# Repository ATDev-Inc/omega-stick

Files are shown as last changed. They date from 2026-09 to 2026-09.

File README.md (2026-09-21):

# Omega Stick

Omega Stick

**A low-force joystick for people with disabilities.** Omega Stick is an
accessible input device for computer control and gaming. Actuation force is
adjustable across roughly 5 to 25 grams and defaults to under 10.





This repository holds the **firmware**: an ESP-IDF project for the ESP32-S3,
written in C++20 on top of the [ESP++ (espp)](https://github.com/esp-cpp/espp)
component library.

## Contents

- [Why low force](#why-low-force)
- [Project status](#project-status)
- [Documentation](#documentation)
- [Hardware](#hardware)
- [Getting started](#getting-started)
  - [Prerequisites](#prerequisites)
  - [Build and flash](#build-and-flash)
  - [Expected output](#expected-output)
- [Repository layout](#repository-layout)
- [Contributing](#contributing)
- [License](#license)
- [Acknowledgements](#acknowledgements)

## Why low force

Conventional joysticks use a mechanical gimbal and centering springs. You have
to physically push against that spring on every input, and the force required is
typically well over 100 grams. For someone with limited strength, reduced range
of motion, tremor, or fatigue, that resistance is the difference between an
input device that works and one that does not.

Omega Stick removes the mechanical resistance from the sensing path. It uses a
**contactless 3-axis Hall-effect sensor** (TI TMAG5273) that measures the
position of a small magnet, so nothing has to be depressed, wiped, or deflected
against a spring to register movement. The actuation force is set by the return
mechanism alone, and is **adjustable from roughly 5 to 25 grams, defaulting
below 10**.

Adjustability matters as much as the floor. Vendors at the low-force frontier
report that a stick can be *too* light to control well, so the usable range
matters more than the minimum, and which point in it works is a property of the
person rather than the device. See D12 in [docs/decisions.md](docs/decisions.md).

Low force on its own is not what makes this project unusual: several sub-10 gram
sticks already ship. They are closed, mostly dealer-gated, and often unpriced.
The gap is the combination of low force with an open design, a plain USB HID
interface, a published price, and a published method for measuring the force
claim. See [docs/PRD.md](docs/PRD.md).

Because the sensing is contactless there is also nothing in the signal path to
wear out, which matters for a device someone may rely on daily.

The stick presents itself to the host over USB as a standard **HID** device, so
it works without drivers or vendor software on the host.

## Project status

**Early development.** This is pre-release firmware and the interfaces are not
stable yet.

What is in the tree today:

- A `TMAG5273` driver ([components/tmag5273/include/tmag5273.hpp](components/tmag5273/include/tmag5273.hpp))
  covering configuration, magnetic X/Y/Z reads, temperature, and conversion status.
- A sensor bring-up application ([main/main.cpp](main/main.cpp)) that probes the
  sensor, dumps its configuration, and streams live magnetic readings to the
  console.

Not implemented yet: the HID report descriptor, axis calibration and centering,
deadzone and response curve shaping, and the USB gamepad/mouse output path. The
`espp/hid-rp`, `espp/joystick`, and `espp/usb_device` dependencies are declared
in [main/idf_component.yml](main/idf_component.yml) in preparation for that work.

If you are looking for somewhere to help, those are the open areas. See
[CONTRIBUTING.md](./CONTRIBUTING.md).

## Documentation

Product and planning documents live in [docs/](docs/):

| Document | Contents |
| --- | --- |
| [PRD.md](docs/PRD.md) | What v1 is, who it is for, scope, and success metrics |
| [requirements.md](docs/requirements.md) | Functional and non-functional specification |
| [decisions.md](docs/decisions.md) | Product decisions with rationale, and what is still open |
| [compliance.md](docs/compliance.md) | What the project may and may not claim about itself |
| [status.md](docs/status.md) | Current working status |
| [research/](docs/research/) | Background research these were built from |
| [assets/logo/](assets/logo/) | Brand marks, wordmark, the animated hero scene, and usage notes |

Research documents are point-in-time snapshots and are not maintained.

## Hardware

The firmware currently targets:

| Part | Notes |
| --- | --- |
| MCU | ESP32-S3, configured via the ESP++ `qtpy` board support |
| Sensor | TI TMAG5273 3-axis Hall-effect sensor, I2C address `0x35`, 400 kHz |
| Bus | Qwiic / STEMMA QT I2C |
| Host link | USB, via TinyUSB |

The mechanical design, PCB, and enclosure are not part of this repository. If
you want to build one, open a
[discussion](https://github.com/ATDev-Inc/omega-stick/discussions) or an issue
and we will point you at what exists.

## Getting started

### Prerequisites

This is an ESP-IDF project targeting **ESP-IDF v5.5.1 or v6.0**. Follow the
[official ESP-IDF getting started
guide](https://docs.espressif.com/projects/esp-idf/en/release-v6.0/esp32s3/get-started/index.html)
to install the toolchain for your platform.

Component dependencies are pulled automatically by the IDF Component Manager
from [main/idf_component.yml](main/idf_component.yml); the resolved set is
pinned in [dependencies.lock](./dependencies.lock). You do not need to vendor
`espp` yourself.

### Build and flash

```console
idf.py set-target esp32s3
idf.py build
idf.py -p PORT flash monitor
```

Replace `PORT` with your serial port (`COM7` on Windows, `/dev/ttyACM0` on
Linux, `/dev/cu.usbmodem*` on macOS). Exit the monitor with `Ctrl-]`.

### Expected output

With a TMAG5273 connected on the Qwiic bus, the bring-up app prints the device
and manufacturer IDs, the active configuration, and then a live stream of
readings. Move a magnet near the sensor and the values should track it:

```
========================================
       TMAG5273 Driver Test
========================================
I2C Address: 0x35
========================================

Probing for TMAG5273...
TMAG5273 found!

X:    1.234 mT   Y:   -0.567 mT   Z:   12.345 mT   T:  24.50 C   Ready: YES
```

If you see `ERROR: TMAG5273 not found at address 0x35`, check the Qwiic cable
and confirm the sensor's address strap.

## Repository layout

```
main/                     application entry point and IDF component manifest
components/tmag5273/      TMAG5273 Hall-effect sensor driver
.github/workflows/        build, packaging, and static analysis CI
sdkconfig.defaults        project-wide ESP-IDF configuration defaults
```

## Contributing

Contributions are welcome, and not only code.

- **Are you a user of assistive technology?** Feedback about how the stick
  actually performs for you is the most valuable input this project can get. You
  do not need to know anything about programming or electronics to file
  [accessibility
  feedback](https://github.com/ATDev-Inc/omega-stick/issues/new/choose).
- **Are you a developer?** See [CONTRIBUTING.md](./CONTRIBUTING.md) for
  environment setup, code style, and the pull request process.

Everyone participating in this project is expected to follow the [Code of
Conduct](./CODE_OF_CONDUCT.md). To report a security issue, see
[SECURITY.md](./SECURITY.md).

## License

Released under the [MIT License](./LICENSE).

## Acknowledgements

Built on [ESP++ (espp)](https://github.com/esp-cpp/espp) and started from the
[esp-cpp/template](https://github.com/esp-cpp/template) project template, both
by [esp-cpp](https://github.com/esp-cpp).

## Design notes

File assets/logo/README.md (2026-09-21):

# Brand assets

Vector marks for Omega Stick. Every mark here is true vector: the omega outline
is 95 cubic Bezier curves with no straight segments, and the wordmark is drawn
rather than set -- straight lines and arcs, stroked with round caps -- so
nothing here depends on a typeface being installed. The folder also holds
two build scripts and three bitmaps, all noted below.

## Files

| File | Use |
| --- | --- |
| `omega.svg` | Primary mark, with outer glow. 96px and up |
| `omega-flat.svg` | Same mark without the blur filter. Below 96px |
| `omega-favicon.svg` | Silhouette only, no rim. Browser tab, 16px and up |
| `omega-mono.svg` | Single colour via `currentColor`. Silkscreen, laser, one-colour print |
| `wordmark.svg` | OMEGA STICK, neon gradient. Generated |
| `wordmark-mono.svg` | OMEGA STICK, single colour via `currentColor`. Generated |
| `lockup.svg` | Mark above wordmark. Default for headers and README. Generated |
| `scene.svg` | The scene as a still. Poster and hero art. Generated |
| `scene-mark.svg` | The same canvas and sky with the floor removed. Generated |
| `omega-neon.svg` | The mark alone with the neon-tube treatment, transparent. Dark grounds only. Generated |
| `scene.html` | The scene as a live hero: constructed mark, lit grid, power-on |
| `build-scene.py` | Regenerates the three scene files above from the constants `scene.html` uses |
| `build-wordmark.py` | Draws the alphabet and regenerates the two wordmarks and the lockup |
| `source-silhouette.png` | Two-colour bitmap the outline was traced from. Kept so the trace is reproducible |
| `source-scene.png` | The render the scene was matched to. Provenance, not a spec |
| `source-scene-knockout.png` | The same render with its background knocked out |

## Palette

| Stop | Hex |
| --- | --- |
| 0% | `#FF12E8` |
| 24% | `#C022FF` |
| 50% | `#7A3BFF` |
| 76% | `#2A8CFF` |
| 100% | `#25D8F2` |

Background used in the scene: `#0B0A2E`. Every scene file lays a sky gradient
over it rather than using it flat -- `#0A0730` overhead to `#1B0A5E` at the
horizon in `scene.html` and `scene.svg`, a shorter ramp in `scene-mark.svg`
which has no horizon -- so sampling a pixel out of a render will not give you
`#0B0A2E`. Use it as the surrounding page colour, not as a colour to match.

## Usage notes

- **Do not scale `omega.svg` below about 96px.** Its Gaussian blur turns to
  mush at small sizes. Use `omega-flat.svg` or `omega-favicon.svg` instead.
  This was checked by rendering both, not assumed.
- **`omega-mono.svg` and `wordmark-mono.svg` inherit `currentColor`**, so set
  `color` on the parent rather than editing the file. That only works when the
  SVG is inlined in the page. Referenced through `<img>` it is a separate
  document, inherits nothing, and comes out black -- so on a dark ground reach
  for `wordmark.svg`, or inline the file.
- **The wordmark is stroked, not filled.** One path of straight lines and
  arcs, `stroke-linecap` and `stroke-linejoin` both `round`, at
  `stroke-width` 17% of the cap height. That is the whole letterform: the round
  terminal is the same tube the mark reads as, which is what makes the two look
  like one drawing in the lockup rather than a symbol next to some type. It
  also means the file stays under 2 kB and the weight is one number.
  **For laser, CNC or vinyl, expand the stroke to outlines first** -- those
  toolpaths follow a stroked path as a centreline and will cut the skeleton
  rather than the letters.
- **The S is the one letter that is not plainly circles and lines.** Each half
  is walked out from the waist as a chain of tangent arcs whose radius tightens
  into the left extreme and opens back out over the top, so the curvature falls
  towards zero at the inflection instead of the letter carrying a straight
  segment through its middle. Its proportions are measured off Century Gothic,
  a geometric face with a truly circular O: there the S is 0.56 of the O's
  width, and this one is 0.62 because a much heavier stroke needs the extra
  room for its counters. The docstring in `build-wordmark.py` records two
  constructions that looked reasonable and were not, so they do not get tried
  again.
- **The S's lower half is wider than its upper half, deliberately.** Draw the
  two congruent and the letter measures symmetrical but reads top-heavy, the
  usual illusion in S, B, X and 8. Every face measured corrects it, by 1.06 in
  Corbel and Verdana up to 1.16 in Century Gothic; this sits at 1.095. The
  waist is nudged left of centre to buy that, and up a little to put the
  inflection where the references put it, both through one `WAIST` constant.
  If the S ever looks wrong at the bottom, check that before the curves: the
  bug people expect is the two halves having drifted apart, and the bug that
  actually shows is them being identical.
- **Nothing in the wordmark is a declared width.** The letters are drawn in a
  100-unit cap height; each one's ink box and both its sidebearings are then
  measured off the shape. A side gets a full bearing where its silhouette is
  flat and less of one the further that silhouette recedes, so `T` tucks under
  its neighbour and `O` sits closer than `I` without anybody kerning pairs by
  hand. Change the weight and the spacing re-solves with it.
- **The round letters are bigger than the cap height, on purpose.** `O`, `C`,
  `G` and `S` overshoot the cap line and the baseline by 1.3 units in 100, and
  the points of `A` and `M` do the same; a circle that stops exactly on the cap
  line reads as too small beside a flat-topped letter. `O`, `C` and `G` stay
  true circles at any weight because their radius is derived from the overshoot
  rather than typed in.
- **The traced outline lives in one place.** All eight SVGs that draw the mark
  carry it byte for byte, and both build scripts read it out of `omega-mono.svg`
  at build time rather than keeping a copy of their own.
- **Mind which space a gradient is in.** The hand-drawn marks use
  `userSpaceOnUse`, and there the rule is: keep the geometry in one coordinate
  space. Wrap parts of a mark in their own transformed groups and each group
  restarts the gradient in its own space, so every piece renders one flat
  colour. The three scene files cannot do that -- the mark and its
  reflection have to sit in differently transformed groups -- so their neon
  gradient is `objectBoundingBox` instead, which is measured per element and
  survives the transform. Copy the right one for the situation.
- `scene.svg` and `scene.html` carry the grid and are deliberately the only
  files that do. The grid is decoration; the mark has to work without it.
- **The wordmark files are generated too; edit `build-wordmark.py`, not them.**
  Run `python assets/logo/build-wordmark.py` to rebuild `wordmark.svg`,
  `wordmark-mono.svg` and `lockup.svg`. It reads the traced outline out of
  `omega-mono.svg` for the lockup, the same way `build-scene.py` does, so the
  trace still lives in exactly one place. The lockup sizes the mark and the gap
  in wordmark cap heights, measured off the mark's real ink box rather than its
  viewBox -- the mark files carry a margin for their glow, and laying out
  against that would put the mark further away than the number says.
- **Three scene files are generated; edit `build-scene.py`, not them.** Run
  `python assets/logo/build-scene.py` to rebuild `scene.svg`, `scene-mark.svg`
  and `omega-neon.svg`. The camera, framing and palette constants at the top of
  that script mirror the custom properties at the top of `scene.html`, so
  `scene.svg` and `scene.html` stay the same picture. They drifted
  badly once -- the SVG had the mark at 55.5% of the frame width against the
  HTML's 38.9%, with the feet on the horizon rather than in front of it and the
  grid at half the pitch -- which is why the geometry is now derived rather than
  drawn. Change one, change the other.
- **The two still differ in the mark outline, on purpose.** `scene.svg` uses the
  traced outline shared with `omega.svg` and the rest of this folder;
  `scene.html` constructs its own from ellipses. They part company slightly
  around the feet. Everything else -- camera, framing, colour ramp, glow, haze,
  reflection, vignette -- matches to a mean of 14/255 per pixel across the
  frame, measured by rendering both.
- **`scene.html` draws the mark from construction, not from the trace.** Outer
  contour: one ellipse. Counter: two half-ellipses sharing a radius, the lower
  one longer. Feet: axis-aligned slabs. It is symmetric about its centre, which
  the traced outline in the other files is not.
- **`scene.html` is switched by data attributes on `.omega-scene`**, and the
  tunable dials are custom properties documented at the top of the file.

  | Attribute | Effect |
  | --- | --- |
  | `data-bg="transparent"` | Drop the sky, stars and vignette, for compositing |
  | `data-motion="calm"` | Still grid, rest of the scene alive. **The default** |
  | `data-motion="on"` | Add the grid drift back on top of the default |
  | `data-motion="off"` | Freeze everything, as `prefers-reduced-motion` does |
  | `data-intro="off"` | Skip the power-on, keep the idle breathe and twinkle |
  | `data-stars="off"` | Drop the starfield, back to flat negative space |
  | `data-crt="on"` | Scanlines and film grain over the whole frame |

- **The grid holds still by default, and that is deliberate.** Perspective
  squares the line weight, so a depth line lands on screen at
  `--lw-z * cos(tilt) * (1 - u)^2` and falls under a pixel wide past `u = 0.61`.
  A sub-pixel line cannot move without its coverage stepping, which reads as
  flicker. Softening the line profile (`--soft-z`), fading the far field where
  lines stop being resolvable, and low-passing the floor together cut the
  measured shimmer by about half -- not enough, so the drift is off unless asked
  for. `data-motion="on"` restores it and `--drift` sets its speed.
- **`omega-neon.svg` needs a dark ground; `omega.svg` does not.** The neon
  treatment is a white rim plus an inner tube highlight and an outer halo, and
  all three of those depend on the background being darker than they are. On a
  near-white card the rim disappears into the page and the halo does nothing,
  leaving a shape that reads as cut out rather than lit. Checked by rendering
  both marks over ink, near-white and mid-violet. Use `omega.svg` on light
  backgrounds and `omega-neon.svg` on dark ones; they share a viewBox and
  intrinsic size, so swapping one for the other moves nothing in a layout.
- **`scene-mark.svg` is the scene with the floor taken out**, not a crop of it.
  The mark recentres, and the sky loses the two light pools anchored to the
  horizon in favour of one centred on the mark -- otherwise the frame reads as
  a scene whose floor failed to load. It is the file to reach for when the
  README note above about the grid being decoration needs demonstrating.
- **The scene was matched to `source-scene.png` by eye, not by measurement,**
  and it cannot be measured. The reference is a soft, glow-heavy render with
  no crisp edge anywhere on the mark: threshold it five different ways and
  the mark's width comes out anywhere from 37% to 55% of the frame, because
  near the feet its bloom floods almost the full width and the horizon band
  below it is brighter than the mark's own rim. `scene.html` settles on
  38.4%, which sits at the sane end of that range. The constants at the top
  of `scene.html` are the authority for framing; these two PNGs are kept as
  provenance, so do not re-derive geometry from them.
- **Set `data-intro="off"` before screenshotting `scene.html`.** The power-on
  runs for 3.2s from load and its first keyframe is a black frame, so a headless
  capture -- which freezes CSS animations at t = 0 -- otherwise gets the unlit
  scene. This was hit while rendering the file, not guessed at.
- **The plane's colour stops are pre-distorted and are tied to `--depth`.** The
  gradient runs down a plane that is then foreshortened, so evenly spaced stops
  would pile up against the horizon. The stops in the file invert that map for
  the current `--depth`; change the depth and they have to be re-solved, or the
  floor's cyan-to-magenta ramp lands in the wrong place. `--fade` is tied to
  `--depth` the same way, and is called out where it is set.

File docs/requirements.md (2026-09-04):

# Omega Stick v1: requirements

Supporting document to [PRD.md](PRD.md). This is the detailed specification;
the PRD is the one-page summary.

Priority: **[M]** must-have for v1, **[S]** should-have, **[C]** could-have.

Evidence behind these requirements is in [docs/research/](research/).

---

## 1. Sensing and signal path

- **SEN-1 [M]** Sample the TMAG5273 X and Y channels continuously at **≥1 kHz**
  from a dedicated pinned FreeRTOS task.
- **SEN-2 [M]** Use the ±40 mT range (x1 part) with **CONV_AVG = 4x**
  (≈3.1 kSPS 3-axis), which gives real noise reduction while staying ~3x faster
  than the sample requirement.
- **SEN-3 [S]** Add an XY-only 4-byte burst read. The driver currently bursts 6
  bytes from `X_MSB_RESULT`; XY-only is ≈158 µs against ≈202 µs at 400 kHz.
- **SEN-4 [S]** Use the sensor's `INT` pin as data-ready if the board exposes it,
  rather than polling on a timer.
- **SEN-5 [M]** Detect sensor loss (I2C failure, or conversion-ready stuck)
  within **500 ms** and surface it per STA-2.
- **SEN-6 [M]** On sensor loss, hold all axes at center rather than transmitting
  the last value or garbage. A stuck-full-deflection axis is an actively harmful
  failure for someone driving a pointer.

## 2. Calibration and centering

- **CAL-1 [M]** Capture a center reference at boot from the resting position.
- **CAL-2 [M]** Provide a guided calibration routine invoked **on the device
  itself**, requiring no host software and **no dedicated control**: capture
  center, then capture the user's reachable extents per axis. Invoked by a stick
  gesture (for example, hold full deflection in one corner for 3 seconds), so it
  costs nothing in the BOM and works with no computer attached. Also invocable
  from the configuration page (CFG-1).
- **CAL-3 [M]** Calibration must be completable by a user who cannot see a
  console. Signal each stage through STA-1.
- **CAL-4 [M]** Map the user's *actual* reachable range to full output range,
  per axis and independently. A user who can reach 30% travel left and 80% right
  must still get full output in both directions.
- **CAL-5 [M]** Slow idle drift correction: when input sits within the deadzone
  for a configurable dwell, migrate the center reference at a rate slow enough
  that it cannot fight deliberate sustained input.
- **CAL-6 [M]** Persist calibration to NVS and restore on boot (see PER-1).
- **CAL-7 [S]** Provide a one-action reset to factory defaults that does not
  require a host.

> Runtime re-centering is mandatory because the TMAG5273 has **5% typical
> sensitivity drift** across temperature, and its on-chip offset registers are a
> static trim rather than drift tracking.

## 3. Response shaping

- **RSP-1 [M]** Configurable center deadzone, radial, default small but nonzero.
- **RSP-2 [M]** Configurable outer (range) deadzone, so full output is reached
  before mechanical end-stop.
- **RSP-3 [M]** Selectable response curve: linear (default) and exponential.
  `espp::FloatRangeMapper` is linear only; `bezier.hpp` is the building block for
  the curve.
- **RSP-4 [M]** Per-axis inversion and axis swap, for users mounting the device
  at an arbitrary orientation.
- **RSP-5 [S]** Per-axis gain scaling. Gain adjustment is one of the few tuning
  parameters with a measured, statistically significant benefit for this
  population (p<0.05, n=16).
- **RSP-6 [S]** Single-axis lock mode, for users who cannot isolate one axis from
  the other.
- **RSP-7 [C]** Selectable tremor filter, **default off**, user-defeatable, with
  the ability to A/B it without a host.

> Tremor filtering defaults off because the one controlled trial of adaptive
> (WFLC) filtering found **no performance improvement** and possible damping of
> intended motion. Fixed low-pass is worse: MS tremor at 3.5 to 5.0 Hz overlaps
> intentional movement.

## 4. Host output

- **OUT-1 [M]** Enumerate as a USB HID device requiring no driver installation on
  Windows 10/11, macOS, Linux, ChromeOS, and Android.
- **OUT-2 [M]** Gamepad report: X/Y (left stick), Z/RZ (right stick), 4-bit hat,
  and buttons.
- **OUT-3 [M]** Mouse report: relative X/Y motion plus at least left and right
  buttons.
- **OUT-4 [M]** Mode selection between gamepad and mouse is made **from the host**
  via the configuration surface (CFG-1), not from a control on the device. The
  selection **persists to NVS** and is restored on boot, so the device keeps its
  mode when later connected to a host that cannot configure it (XAC, console,
  tablet). Switching must not cause re-enumeration.
- **OUT-5 [M]** Set HID `bInterval` to **1 ms**. `espp::UsbDevice`'s
  `HidFunction` defaults `poll_interval_ms` to 10, which is only 100 Hz. **This
  default must be overridden explicitly.**
- **OUT-6 [M]** Send reports on change, decimated from the ≥1 kHz sample task.
- **OUT-7 [M]** Keep HID reports **at or under 64 bytes**. There is a known
  ESP-IDF endpoint-stall defect with consecutive reports above 64 bytes.
- **OUT-8 [M]** Expose the interface the configuration page needs (WebHID feature
  reports, or a WebUSB vendor interface) in the same TinyUSB composite. **Raised
  from [S] to [M] because CFG-1 now depends on it.** Also expose a CDC-ACM
  interface for logging and a fallback configuration CLI, for developers and for
  users whose browser cannot reach the config page.
- **OUT-9 [S]** Verify against the XAC's documented external-joystick mapping
  (X/Y to left stick, Z/RZ to right stick, hat to d-pad), which requires **XAC
  firmware June 2024 or newer**. Default button mapping for external USB joystick
  buttons is reported as unexpected and needs bench confirmation.

## 5. Configuration

- **CFG-1 [M]** Configuration is performed from a **browser-based configuration
  page requiring no installed software** (WebHID or WebUSB). Every parameter in
  sections 2 and 3 marked [M], plus output mode (OUT-4), is settable there.
- **CFG-2 [M]** Every setting **persists to NVS** (PER-1) and survives replug,
  power loss, and a change of host. A user configures once on a computer and the
  device keeps that configuration on an XAC, console, or tablet.
- **CFG-3 [M]** The device is fully functional at first plug-in with factory
  defaults. Configuration is never a prerequisite.
- **CFG-4 [M]** The configuration page must be usable by someone operating the
  computer with the Omega Stick itself, or with whatever input device they
  already use. Large targets, keyboard-reachable, no drag-only interactions, no
  timed interactions. It is an accessibility product: its own settings UI is the
  first thing a user touches.
- **CFG-5 [S]** Support at least two stored profiles (for example a gaming
  profile and a pointer profile).

> **Design principle 2 ("no required host software") is satisfied in spirit but
> narrowed.** A browser page installs nothing, but it does make the *changing* of
> settings host-dependent. CFG-2 is what keeps the device itself
> host-independent: the configuration travels with the device, not the host.
> **CAL-2 deliberately stays on-device**, because recalibration is the one thing
> a user may genuinely need in the field with no computer present.

## 6. Status and failure visibility

- **STA-1 [M]** A non-console status channel (LED or equivalent) that
  distinguishes at minimum: healthy, calibrating, calibration stage advanced,
  sensor fault, and configuration saved.
- **STA-2 [M]** Sensor faults, calibration faults, and NVS faults are each
  distinguishable through STA-1, not merged into one generic error.
- **STA-3 [S]** Status must be perceivable without relying solely on color, since
  the user population overlaps with color vision deficiency.

## 7. Persistence

- **PER-1 [M]** Calibration, configuration, and **selected output mode** persist
  in NVS across power cycles, host changes, and firmware updates within a major
  version. This is what makes host-side configuration (CFG-1) acceptable on hosts
  that cannot configure.
- **PER-2 [M]** Corrupt or absent stored configuration falls back to defaults and
  reports through STA-2, rather than failing to boot.
- **PER-3 [S]** Store a schema version so future firmware can migrate or safely
  reject old records.

## 8. Non-functional

- **NFR-1 [M]** End-to-end latency, stick motion to HID report on the wire,
  **≤5 ms** at the 95th percentile. The computed budget is ~2 to 3 ms at a 1 ms
  bInterval; the sensor and I2C path together are under 0.5 ms and are never the
  bottleneck.
- **NFR-2 [M]** Sustained operation for **≥8 hours** with no drift requiring
  manual recalibration.
- **NFR-3 [M]** No dynamic allocation in the sample or report path.
- **NFR-4 [S]** Set `CONFIG_FREERTOS_HZ=1000` and 240 MHz CPU in
  `sdkconfig.defaults`. Both are currently commented out.
- **NFR-5 [S]** Sustained 1 kHz HID reporting on ESP32-S3 + TinyUSB is
  **unverified**; no published benchmark was found. Bench-measure early and
  revise NFR-1 if it proves unattainable.

---

## 9. Hardware interface requirements

**Not owned by this repository.** Stated because the product claims depend on
them. See the scope note in the [PRD](PRD.md).

- **HW-1 [M]** Actuation force **adjustable across approximately 5 to 25 gf**,
  with the shipped default **at or below 10 gf**. Pending the design-principle
  decision in the PRD.
- **HW-2 [M]** A **documented, repeatable force and throw measurement protocol**,
  published with results. ISO 9241-410 (ergonomic design of physical input
  devices, explicitly covering joysticks) is the natural framework to cite.
  No competitor publishes a method; several disagree with third-party
  measurements of their own products.
- **HW-2a [M]** The protocol must be **performable by the person who printed the
  device, using household items** (for example a set of known small masses or a
  kitchen scale), not laboratory equipment. Because the enclosure is 3D printed
  by third parties, this is not documentation, it is the **only quality control
  the design has**. See HW-9.
- **HW-3 [M]** Mounting: **1/4"-20 UNC insert** plus the **AMPS 4-hole pattern
  (30 mm x 38 mm)**. That combination reaches RAM Mounts (1" B ball is the
  practical AT size), the Rehadapt Universal Device Socket (and through it
  VESA 75/100, Daessy, Armon Edero, LC-Tech), and matches the Xbox Adaptive
  Joystick convention. Negligible BOM cost, large ecosystem reach.
- **HW-4 [S]** Compatibility with the special-controls ecosystem's 6 mm rod and
  half-clamp hardware.
- **HW-5 [M]** USB bus-powered, **no battery**. A cell would trigger UN 38.3
  transport and IEC 62133-2 product-safety obligations for no v1 benefit.
- **HW-6 [M]** Expose the TMAG5273 `INT` pin to a GPIO (enables SEN-4).
- **HW-7 [S]** Magnet and sensor geometry chosen so that full mechanical throw
  maps to a large fraction of the ±40 mT range, maximizing usable resolution of
  the 12-bit ADC (one LSB ≈ 19.5 µT at that range).
- **HW-8 [M]** User-replaceable wear parts, with spares and drawings published.
  Since the body is printed, a worn part should be **reprintable rather than
  ordered**. Repairability is a direct countermeasure to the documented
  abandonment predictors.
- **HW-9 [M]** **Design for print-tolerance variance.** At a 5 to 10 gf budget,
  friction in the return mechanism is most of the specification, and print
  tolerance, layer adhesion, and surface finish vary between machines, materials,
  and successive prints on one machine. A few grams of unintended friction
  consumes the entire budget. Required:
  - Publish tested filament types, layer heights, orientations, and tolerances,
    and state which are known not to work.
  - Prefer **non-printed parts for the friction-critical path** (bearings,
    bushings, pivots, and the return element itself) sourced as standard
    off-the-shelf components, so the printed part positions them rather than
    being the tribological surface.
  - Provide a **printed test coupon or go/no-go gauge** so a builder can check
    their printer before committing to a full build.
  - Publish the acceptance criterion the HW-2a measurement has to meet.
- **HW-10 [S]** Magnet-to-sensor geometry should be **tolerant of the stack-up
  variance a printed assembly introduces**. Firmware calibration (CAL-4) already
  maps each user's actual reachable range, which absorbs a useful amount of
  per-unit geometric variation for free; the mechanical design should lean on
  that rather than demand tight tolerances it cannot enforce.

---

## 10. Host compatibility matrix

| Host | Gamepad mode | Mouse mode | Notes |
| --- | --- | --- | --- |
| Windows 10/11 | Yes (DirectInput / `RawGameController`, appears in `joy.cpl`) | Yes | **Not XInput.** Many modern titles are XInput-only and will not see it. Steam Input is the documented workaround |
| macOS | Yes (IOKit HID) | Yes | **Not `GCController`.** Apple's GameController.framework gates on MFi/Xbox/DualSense PnP IDs; generic pads produce no controller object. Open Apple bug on file |
| Linux | Yes (evdev/joydev) | Yes | Essentially unclaimed by competitors |
| ChromeOS | Yes | Yes | |
| Android | Yes (`SOURCE_GAMEPAD`) | Yes | |
| **iOS / iPadOS** | **No** | **Yes** | Mouse via AssistiveTouch pointer is fully supported and is **the only working mode**. Reports suggest exotic composite descriptors can make iOS ignore a device entirely: bench-verify early |
| Xbox (via XAC USB-A) | Yes | n/a | Requires XAC firmware June 2024+. No licensing needed |
| Xbox (direct) | **No** | **No** | Blocked, error `0x82d60002` |
| PlayStation 4/5 (direct) | **No** | **No** | Requires cryptographic auth |
| Nintendo Switch (direct) | **No** | **No** | Requires proprietary handshake |

Full analysis: [research/03](research/03-hid-platform-compatibility.md).

---

## 11. Known defects to fix first

Found while surveying the existing driver. Both block milestone M-A.

### DEF-1: magnetic range conversion is wrong for every part variant

[`components/tmag5273/include/tmag5273.hpp:770`](../components/tmag5273/include/tmag5273.hpp#L770)
returns `266.0f` unconditionally, and
[line 754](../components/tmag5273/include/tmag5273.hpp#L754) consumes it as the
**LOW** full-scale, doubling it for HIGH. That yields LOW = 266 mT / HIGH = 532
mT, which matches neither variant:

| Part | LOW | HIGH |
| --- | --- | --- |
| A1 | ±40 mT | ±80 mT |
| A2 | ±133 mT | ±266 mT |
| **Code produces** | **266 mT** | **532 mT** |

Reported values are therefore **~6.65x high on an A1** and **~2x high on an A2**.
The in-code comment acknowledges the hardcoding.

### DEF-2: `range_z_mT()` is dead code

[Line 773](../components/tmag5273/include/tmag5273.hpp#L773) is never called.
`convert_raw_to_mT` always reaches for the XY constant even when callers
correctly pass `z_range_`. Numerically harmless only because both constants are
currently the same literal, which stops being true the moment DEF-1 is fixed in
isolation.

> Because joystick math runs in **raw counts**, neither defect can affect how the
> device feels. Both corrupt any published measurement and any bench validation,
> which matters because HW-2 makes a published force protocol part of the
> product's positioning.

### Also unused, worth wiring

- `INT_CONFIG_1`: enables SEN-4 (data-ready interrupt)
- `MAG_OFFSET_CONFIG_1/2`: on-chip static trim, distinct from runtime re-centering
- `MAG_GAIN_CONFIG`

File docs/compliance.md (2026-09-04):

# Omega Stick v1: claims and compliance constraints

Supporting document to [PRD.md](PRD.md). These are constraints on **what the
project may say**, which is why they belong alongside the product spec rather
than in a separate legal file.

**Not legal advice, and not a regulatory analysis.** This records what the
project will and will not claim about itself. Supporting research on funding and
product compliance is in [research/04](research/04-funding-and-compliance.md).

**Point-in-time snapshot.** Compiled during v1 planning and not actively
maintained. Re-check anything here before relying on it.

---

## 1. Prohibited claims

Omega Stick v1 must be described **only** as a computer and gaming input
peripheral for accessibility. Specifically prohibited:

- Any **therapeutic, diagnostic, rehabilitative, or treatment** claim.
- Any claim positioning it as a **communication device for people with medical
  impairments**.
- Any **wheelchair drive-control** capability.
- **"ADA compliant."** The ADA creates obligations for covered entities rather
  than a product certification, so there is no such mark for a peripheral to
  carry. (Inference from how the statute is structured, UNVERIFIED.)

### Why this is a hard constraint, not a style preference

Medical, therapeutic, and communication-device claims carry obligations that a
general-purpose input peripheral does not. How a product describes itself is
what determines which category it lands in, so the wording is a product
constraint rather than a matter of marketing taste.

This project has taken no regulatory advice and nothing here substitutes for it.
If the scope ever moves toward a medical or communication device, that needs
qualified counsel before anything ships.

Keep a documented prohibited-claims list and review published copy against it.

### The wheelchair line

Wheelchair drive control is a hard non-goal, not a deferred feature. A drive
input is a safety-critical part of a mobility system, which is a different
product category carrying a different set of obligations.

---

## 2. Compliance obligations for v1 as scoped

Wired, USB bus-powered, no radio, no battery:

| Region | Obligation |
| --- | --- |
| **US** | FCC Part 15 Subpart B, Class B, authorized by **SDoC**. Requires a US responsible party, a compliance information statement, and labeling |
| **EU** | EMC Directive 2014/30/EU, RoHS, REACH, WEEE producer registration. **RED does not apply** without a radio |
| **UK** | Accepts CE indefinitely (2024 extension) |

### Not applicable at this scope

RED, UN 38.3, IEC 62133-2, and modular radio integration paperwork.

> **All of these arrive the moment BLE or a battery ships.** That is the main
> practical reason for decisions D1 and HW-5.

### USB identifiers

| Option | Cost |
| --- | --- |
| USB-IF VID | **$6,000**, sharing forbidden |
| **Espressif VID `0x303A`** | **Free**, PID allocated by pull request |
| pid.codes | Free, fallback |

### If BLE ever ships

FCC clarified that open-source firmware is permitted **as long as it cannot
alter RF operating characteristics**. Architect the firmware now with a
separated RF/config layer so a future BLE variant does not force the project
closed.

---

## 3. Standards to cite

| Standard | Use |
| --- | --- |
| **ISO 9241-410** | The framework for the HW-2 force and throw measurement protocol. Explicitly covers joysticks |
| **ISO 9999** | Assistive product class, for tender and catalog documentation |
| **Section 508 Chapter 4 (Hardware)** and **EN 301 549** | Publish a **VPAT / Accessibility Conformance Report** |

> Institutional and government buyers ask for a VPAT, and **its absence blocks
> procurement outright.** EN 301 549, unlike WCAG, contains substantial hardware
> requirements and is what buyers cite for physical products.

---

## 4. Open source

- **Keep MIT** for firmware. Obligations are minimal and fully compatible with
  selling hardware.
- **Audit and preserve upstream third-party NOTICE files** before shipping
  binaries. ESP-IDF components are largely Apache-2.0.
- **Pursue OSHWA certification.** Free, self-certifying, annually renewed. The
  TMAG5273 has a public TI datasheet, so the third-party documentation condition
  is satisfiable. It is a credible trust signal to AT funders and the disability
  community, and the nearest competitor (Willow) already holds one.

**No conflict** was found between open sourcing and the compliance regimes that
apply to v1 as scoped. Two friction points only:

1. If BLE ships, RF parameters must not be user-modifiable.
2. If the product scope ever changed such that a formal quality system applied,
   community pull requests would need a gated release process feeding a
   controlled build.

---

## 5. Funding pathways

**Do not build the business case on Medicare.** General-purpose computer access
fails the "primarily and customarily used to serve a medical purpose" test, and
devices that can be unlocked for general computing are coded **A9270,
non-covered**.

### Realistic channels for v1

| Channel | Notes |
| --- | --- |
| **State AT Act programs** | ACL-funded: device loan, reuse, demonstration |
| **Vocational Rehabilitation** | Funds AT that enables employment |
| **IDEA / IEP** | District must fund AT written into the IEP, **at no cost to the family** |
| **VA** | Assistive technology and PSAS programs; VA medical centers have received Xbox Adaptive Controllers |
| **AbleGamers** | Supplies equipment free after an expert consult, though applications have been paused for demand |

### The SGD accessory route, and why it conflicts

If pursued, the code is **E2599** (accessory for a speech generating device, not
otherwise classified). It requires pairing with a covered **dedicated** SGD plus
an SLP evaluation naming the specific access method.

> **This channel and general-purpose positioning are mutually exclusive.**
> Marketing "it's also a general computer and gaming device" is exactly the
> language that pushes items to A9270 non-covered. **One SKU cannot do both.**
> v1 chooses general-purpose positioning; E2599 is out of scope.

### Funder documentation as a deliverable

Whatever the channel, funders typically require a physician face-to-face note,
an SLP or clinician evaluation naming the access method and why standard input
cannot be used, a written order prior to delivery, and per-item medical-necessity
justification.

Treat the documentation package as a product deliverable: a clinician-facing
evaluation template, a letter-of-medical-necessity template, and a spec sheet
quantifying actuation force and throw (which HW-2 produces anyway).

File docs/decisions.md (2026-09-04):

# Omega Stick v1: product decisions

Supporting document to [PRD.md](PRD.md). Each decision records **why**, so it is
not relitigated per pull request. Evidence is in [docs/research/](research/).

---

## D1: USB wired only in v1. No BLE.

The ESP32-S3 has **BLE only, no Bluetooth Classic**
([ESP-IDF docs](https://docs.espressif.com/projects/esp-idf/en/stable/esp32s3/api-guides/ble/overview.html)),
so Bluetooth Classic HID is impossible regardless of preference.

BLE would trigger FCC Part 15 Subpart C and EU RED obligations (RED applies to
the whole product and subsumes EMC/LVD; module pre-certification does not remove
device-level assessment). And **iOS and macOS reject generic BLE HID gamepads**
the same way they reject generic USB ones.

> BLE costs real compliance work and buys no platform. Deferred to a separate
> compliance-gated milestone.

## D2: Composite HID, gamepad and mouse on one interface, two report IDs

Mouse is the **only mode iPadOS accepts** and the universal fallback. Gamepad is
what games need. Mode switching changes which report is sent, **never the
descriptor**, so the host never re-enumerates.

The AT field precedent is Makers Making Change's OpenAT joysticks, which ship
"USB HID Mouse or USB HID Gamepad" with a **physical mode-cycle switch**. Omega
Stick differs here: see D11.

**Risk:** Apple forum reports suggest exotic or composite descriptors can make
iOS ignore a device entirely. Bench-verify on iPadOS early, since that is the
platform where mouse mode is the only option.

## D11: Mode and configuration are set from the host, then persisted

**Decision:** there is **no physical mode control**. Output mode, deadzone,
response curve, gain, and axis inversion are all set from a browser-based
configuration page that installs nothing, and **every setting persists to NVS**.

**Why persistence carries the design.** The device is configured once on a
computer and then keeps that configuration everywhere, including on an XAC, a
console, or a tablet where no configuration is possible. The configuration
travels with the device rather than with the host, which is what keeps design
principle 2 substantially intact even though the *act* of configuring is now
host-dependent.

**What this costs:**

- A user whose only computer cannot reach the config page cannot change mode.
  They get whatever the device was last set to, or the factory default.
- Browser support for the underlying APIs is **not universal**. This is being
  verified; see the open item below.

**What preserves the escape hatch:** calibration stays on-device (CAL-2),
invoked by a **stick gesture** rather than a dedicated control, so it costs
nothing in the BOM and works with no computer present. Recalibration is the one
adjustment a user may genuinely need in the field, for example after remounting.

**Alternative rejected:** an installed configuration app. That violates design
principle 2 outright, and on locked-down school and work machines (an explicitly
targeted environment) the user often cannot install anything.

> **Open item.** If browser support turns out to be narrow, the mitigation is not
> to add an app but to make the factory defaults genuinely good, keep the CDC
> fallback CLI, and consider whether a stick-gesture mode toggle should be added
> back at zero BOM cost, since buttons already exist for mouse click (OUT-3).

## D3: Descriptor shape is X/Y, Z/RZ, 4-bit hat, N buttons

This is the mapping the XAC expects, so the stick lands on the left thumbstick
with no licensing. `espp::GamepadInputReport` provides exactly this layout
already (X/Y left stick, Z/RZ right stick, 2 triggers, 4-bit hat, N buttons).

Caveat: `get_descriptor()` returns a fragment the caller must wrap in
`usage_page<generic_desktop>` / `usage(GAMEPAD)` / `collection::application`.

## D4: Console support routes through the XAC USB-A port, not direct

Direct connection is closed on all three consoles:

- **Xbox** blocks unlicensed accessories with error `0x82d60002` (since November
  2023), requiring "Designed for Xbox" licensing and an auth IC.
- **PS5** requires DualSense cryptographic auth; PS4 mode needs uploaded
  encryption keys.
- **Switch** requires a proprietary handshake, not generic USB HID.

Microsoft confirmed the accessory block has **"no impact to players using the
Xbox Adaptive Controller regardless of the peripherals plugged into its USB and
3.5mm ports."** The XAC is the legitimate exemption, and the console only ever
sees the licensed XAC.

The `dinput_pluggable` project documents the working mapping and requires **XAC
firmware June 2024 or newer**.

## D5: Steam Input is the documented answer to XInput-only games

Windows never exposes generic HID via XInput; that is reserved for Microsoft's
XUSB descriptor set. Many modern titles are XInput-only and will not see the
stick at all.

Steam Input reads generic HID and injects a virtual Xbox pad into any
Steam-launched game. ViGEmBus is archived (November 2023). True Xbox emulation
requires the proprietary descriptor plus auth silicon and is **not a legitimate
path**.

## D6: All joystick math in raw sensor counts, not millitesla

Physical-unit conversion is a display concern. Working in raw counts also
isolates the feel of the device from the conversion defect recorded as DEF-1 in
[requirements.md](requirements.md).

## D7: Runtime re-centering is mandatory, not optional

The TMAG5273 has **5% typical sensitivity drift** across temperature, and its
on-chip offset registers are a static user trim rather than drift tracking.
Boot capture plus slow idle drift correction.

## D8: Tremor filtering ships available and defaulted off

This is a **documented negative result**, not an absence of evidence.

- The one controlled trial of adaptive (WFLC) filtering **found no performance
  improvement** and possible damping of intended motion (Dicianno et al., JRRD
  2009).
- Fixed low-pass is worse: **MS tremor runs 3.5 to 5.0 Hz**, overlapping
  intentional movement, so a cutoff low enough to remove it introduces phase lag
  and deletes real commands.

Ship it, default it off, make it defeatable, let users A/B it.

## D9: Both displacement and isometric-style response modes, selectable

The literature is genuinely split:

| Study | Finding |
| --- | --- |
| Cooper et al., IEEE TBME 2000 | Isometric gave **fewer movement errors but longer reaction times** |
| Dicianno et al., JRRD 2009 | Isometric **preferred by participants with tremor** |
| Stewart, Aust Occup Ther J 1992 | Displacement **superior for 4 of 5 CP subjects with prior displacement experience** |

Configurability is the evidence-backed answer. Committing to one architecture is
not.

## D10: Free PID under Espressif's VID `0x303A`

USB-IF charges **$6,000** for a VID and forbids sharing it. Espressif allocates
PIDs by pull request for projects using an Espressif chip with a USB interface,
at no cost and with no endorsement implied. pid.codes is the fallback.

---

## D12: Actuation force is adjustable, defaulting below 10 gf

The device must reach **under 10 gf** and must let the user select a higher
force. Target range **5 to 25 gf**, defaulting below 10.

**Why.** Two independent vendors at the low-force frontier report that too-light
is a real failure mode:

- Celtic Magic states that *"an extremely light force stick can be just too light
  and in practice be harder to use"*, and ships a 4-step 5/10/16/20 gf magnet
  adjustment for exactly this reason.
- mo-vis warns its 5 gf adapted Micro requires *"special attention to mounting,
  shielding and testing."*

Minimum force is therefore the wrong thing to optimise on its own. The usable
range matters more, and which point in it works is a property of the individual
user, not of the device.

**Consequence.** Design principle 1 in [CONTRIBUTING.md](../CONTRIBUTING.md) was
amended. As originally worded it forbade adding mechanical resistance to the
input path, which would have ruled out the adjustment mechanism this decision
depends on. It now constrains the *minimum* achievable force instead.

**Consequence.** The README no longer presents "under 10 grams" as the
differentiator on its own, which matches section 5 of [PRD.md](PRD.md).

---

## Open question: compete with Willow, or collaborate?

**Willow** (Makers Making Change) already occupies most of the position this
project is aiming at: open source (CERN-OHL-W-2.0 + GPL-3.0), OSHWA-certified,
contactless Hall-effect sensing, USB HID mouse and gamepad, ~$180 BOM, and backed
by an established volunteer fabrication network that can actually get devices to
individuals.

It sits at **25 gf**. That is the gap, and on current evidence it is the only
substantial one.

Before committing to differentiation, the honest question is whether the people
this project exists to serve are better off with a competing open joystick or
with a low-force contribution to an ecosystem that already has distribution,
certification, and a maker network. Options worth weighing:

- Ship independently and differentiate on force range, the measurement protocol,
  and price.
- Contribute a low-force variant or return mechanism into the OpenAT family.
- Ship independently but deliberately match their mounting, licensing, and
  fabrication conventions so parts and knowledge transfer between the two.

Deciding this late is more expensive than deciding it now, because it affects
licence choice, mechanical interfaces, and how the project introduces itself.

## Out of scope for v1

Explicitly excluded, with the reason, so these are not relitigated per pull
request.

| Item | Reason |
| --- | --- |
| **Wheelchair drive control** | Safety-critical part of a mobility system. A different product category with a different obligation set, not a feature. See [compliance.md](compliance.md) |
| **BLE / wireless** | D1. Compliance cost with no platform gain |
| **Direct console connection** | D4. Requires licensing or auth silicon |
| **Analog TRRS output to XAC X1/X2 ports** | Viable (Tip = axis 1, Ring1 = axis 2, Ring2 = GND, Sleeve = 3.3 V ref) but needs a DAC and a hardware variant. Revisit for v2 |
| **Companion configuration app** | Design principle 2. Optional CDC CLI only (OUT-8) |
| **Head / eye / sip-and-puff / voice input** | Different product |
| **Battery power** | HW-5. Triggers UN 38.3 and IEC 62133-2 for no v1 benefit |
| **Any medical or therapeutic claim** | See [compliance.md](compliance.md). Changes what category the product is treated as |

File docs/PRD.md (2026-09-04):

# Omega Stick: Product Requirements Document

| Field | Value |
| --- | --- |
| **Version** | v1 |
| **Date** | 2026-09-04 |
| **Status** | Draft for review |
| **Product** | Low-force accessible joystick for computer control and gaming |
| **Repository** | `ATDev-Inc/omega-stick` |

**Supporting documents:** [requirements](requirements.md) (full specification) ·
[decisions](decisions.md) · [compliance](compliance.md) · [research](research/)

---

## 1. Product summary

Omega Stick is a joystick whose actuation force is adjustable across roughly 5
to 25 grams and defaults to under 10, intended for people who cannot operate a
conventional spring-centred joystick. It connects by USB, presents as a standard
input device requiring no installed software, and works across computers,
tablets, and games consoles.

The device is open source and **designed to be 3D printed**, so that it can be
produced locally by users, families, schools, and maker networks rather than
obtained solely through clinical supply channels.

## 2. Problem statement

Conventional joysticks place a spring between the user and the input. Standard
wheelchair joysticks require **200 to 336 grams of force** at full deflection.

| Evidence | Finding |
| --- | --- |
| Measured pinch strength, DMD and SMA adults | **1.4 to 1.6 kg**, approximately 20% of predicted |
| Pointing task error rates, users with physical disabilities | **Above 10% for 14 of 20 participants; 55% of drag tasks failed** |

The requirement addresses sustained use, not single actuation.

## 3. Target users

**Primary.** People with reduced strength, range of motion, or endurance arising
from SMA, ALS, muscular dystrophy, cerebral palsy, spinal cord injury (notably
C4 to C6), multiple sclerosis, arthritis, or essential tremor.

**Secondary.** Occupational therapists and assistive technology professionals
specifying equipment; caregivers and family members mounting and maintaining it;
maker networks and volunteer fabricators building units for individuals.

**Market sizing.** Approximately **250,000 people in the US cannot operate a
powered wheelchair**, with researchers estimating **half could with improved input
technology**. Computer use falls from 85% among people without disability to
**63% among those with severe dexterity impairment**. Approximately **46 million
US gamers have a disability**. Globally, **2.5 billion people require an assistive
product and approximately 1 billion have no access**, ranging from 90% access in
high-income countries to **3% in low-income countries**.
([evidence](research/02-user-needs-and-evidence.md))

## 4. Strategic rationale: open source

Open source is a product requirement, not a licensing preference. It addresses
four documented failure modes in this market.

| Failure mode | Evidence | How open source addresses it |
| --- | --- | --- |
| **Vendor exit strands users** | Ability Drive defunct; Traxsys exited AT; Switch-It MicroPilot discontinued (the only sub-10 g zero-throw device); QuadStick sold out on weekly allocation; mo-vis and Celtic Magic quote-only | Published designs and firmware outlive the originating organisation. Users retain the ability to repair, rebuild, and adapt independently |
| **Device abandonment** | **29% of assistive devices abandoned**, mobility aids highest. Leading predictors: user opinion not considered at selection, poor performance, changing user needs | Open development admits users as contributors; published spares and printable parts address changing needs and wear |
| **Access is gated** | Sub-10 g devices are dealer-gated, requiring a wheelchair, clinician, and insurance authorisation; one is approximately $3,300. Two-thirds of AT users worldwide self-fund | Local fabrication removes the supply chain as a gate. A printed unit reaches users no distribution channel serves |
| **No product fits every body** | Existing devices optimise for a median user that does not exist in this population | Users, therapists, and local makers modify the design directly rather than requesting a vendor roadmap change |

**Competitive note.** No commercial assistive technology joystick publishes
schematics or firmware. QuadStick publishes 3D files only; Celtic Magic reserves
all rights. Open source is therefore differentiating in this category, though not
unique: Willow, from a volunteer maker network, is open and certified.

**Commitments.** Permissive firmware licence retained; **OSHWA certification**
pursued (free, and the recognised trust signal for this audience); mechanical
files published.

## 5. Market positioning

**Actuation force alone is not differentiating.** Sub-10 gram devices already
ship: mo-vis Micro (8.5 g), ASL Molecule (8 g), Celtic Magic Feather (adjustable
to 5 g). All are closed, predominantly dealer-gated and unpriced, and several
operate only through proprietary wheelchair control systems.

**The unoccupied position is the combination:**

> Adjustable **5 to 25 grams** defaulting below 10 · functions as **both game
> controller and mouse** · Windows, macOS, **Linux**, Android, and Xbox ·
> **open source and 3D printable** · **published price below approximately $200** ·
> **published force-measurement method**

No vendor in this category publishes a force-measurement method, and independent
measurements contradict vendor claims where both exist.
([landscape](research/01-competitive-landscape.md))

## 6. Goals

| # | Goal | Acceptance criterion |
| --- | --- | --- |
| G1 | Immediate usability | Functional within 60 seconds of connection, with no installation, account, or clinical appointment |
| G2 | Dual output modes | Operates as game controller or mouse, selected on a host and retained by the device |
| G3 | Broad host support | Driverless operation on Windows, macOS, Linux, ChromeOS, Android; Xbox via the Xbox Adaptive Controller |
| G4 | Adjustable to the individual | All body-dependent parameters configurable and persisted to the device |
| G5 | Visible failure | Fault states distinguishable by a non-technical user with no console attached |
| G6 | Reproducible | Rebuildable from published firmware, mechanical files, and force-measurement method |

## 7. Scope

**In scope for v1:** USB-connected operation; game controller and mouse output;
per-user calibration and response tuning; host-based configuration with on-device
persistence; 3D-printable enclosure; published measurement method.

**Out of scope for v1:** wheelchair drive control; direct console connection;
wireless operation; any installed application as a dependency; medical claims;
head, eye, sip-and-puff, or voice input.
([rationale](decisions.md#out-of-scope-for-v1))

## 8. User stories

| As a | I need to | So that |
| --- | --- | --- |
| User with limited strength | Move the stick without pushing against a spring | I can use a computer for a full working session without exhaustion |
| User with restricted range of motion | Have the device learn my reachable limits | I get full cursor range from the movement I actually have |
| User with tremor | Adjust or disable filtering and response curves | The device follows my intent rather than a vendor's assumption about tremor |
| User on a managed school or work machine | Use it with nothing installed | I am not blocked by IT policy from using my own access device |
| Console gamer | Connect through the Xbox Adaptive Controller | I can play without licensed-accessory restrictions |
| Caregiver | Reposition and remount it quickly | It works at a desk, on a wheelchair tray, and in bed |
| Maker or family member | Print and assemble it from published files | Someone can have one without a supply chain or funding approval |
| Therapist | Cite a documented force specification | I can justify it in an assessment or funding request |

## 9. Requirements summary

Full specification, host compatibility matrix, and known defects:
**[requirements.md](requirements.md).**

| Area | Summary |
| --- | --- |
| **Sensing** | Contactless magnetic sensing, sampled fast enough that latency is imperceptible; safe behaviour on sensor loss |
| **Calibration** | Per-user centre and reach capture; automatic drift correction; on-device invocation with no host required |
| **Response** | Configurable dead zone, response curve, per-axis gain, inversion; tremor filtering supplied but disabled by default |
| **Output** | Game controller and mouse; driverless on all target hosts; Xbox via the Adaptive Controller |
| **Configuration** | Host-based, installing nothing; all settings persisted to the device so they travel with it |
| **Hardware contract** | Adjustable 5 to 25 gf; standard mounting interfaces; bus-powered, no battery; **design tolerant of 3D print variance** |

## 10. Success metrics

| Metric | Target | Rationale |
| --- | --- | --- |
| Time from connection to pointer control, unaided | Under 60 seconds | Complexity is a leading abandonment driver |
| Users completing calibration without assistance | 80% | Removes clinical dependency |
| **Continuous use before reported fatigue** | **2 hours** | **Primary abandonment driver in this population** |
| Sessions requiring manual recalibration | Under 5% | Device performance predictor |
| Target hosts working without drivers | 5 of 6 | |
| **Users with disabilities providing feedback before v1 release** | **10 minimum** | **Strongest single abandonment predictor is that the user was not consulted** |
| Independent successful builds from published files | 3 minimum | Validates the open-source distribution claim |

## 11. Constraints

Omega Stick v1 is positioned exclusively as a computer and gaming input
peripheral for accessibility. **Prohibited:** therapeutic, diagnostic, or
rehabilitative claims; wheelchair drive-control capability; the term "ADA
compliant."

How the product describes itself is what determines the category it is treated
as, so these are product constraints rather than marketing preferences. Details:
[compliance.md](compliance.md).

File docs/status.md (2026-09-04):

# Omega Stick: project status

Working status, kept out of [PRD.md](PRD.md) deliberately: the PRD specifies what
the product must be, not where the work has reached.

**Updated:** 2026-09-04

| Component | Status |
| --- | --- |
| Physical prototype | **Built** |
| Sensor driver | Implemented. Two defects identified, recorded in [requirements.md](requirements.md#11-known-defects-to-fix-first) |
| Sensor bring-up firmware | Implemented, diagnostic only |
| Joystick behaviour, output, calibration, configuration | Not implemented |
| Mechanical files for 3D printing | **Not yet published** |
| Force and throw measurement | **Not yet performed or published** |

## Highest-value next action

**Measure and publish the prototype's actuation force and throw.**

The market positioning in the PRD rests on a force figure. A prototype now exists,
so that figure is obtainable, and it is the one claim the whole document depends
on that has not been substantiated. It also gates the measurement protocol
(HW-2 / HW-2a), which the design needs anyway as the only quality control a
3D-printed, third-party-fabricated device has.

It is not blocked by firmware progress and can be done independently.

## Firmware critical path

Signal path → joystick maths → controller output → mouse mode → calibration and
persistence → Xbox Adaptive Controller validation → user feedback.

The middle of that sequence has no precedent in the library the project builds
on, so it is original work rather than integration.

## Open items requiring a decision

| Item | Where it is recorded |
| --- | --- |
| Adjustable force versus lightest-possible force. **Blocks mechanical design freeze** | [decisions.md](decisions.md#open-decision-design-principle-1) |
| Compete with Willow or collaborate. Affects licence and mechanical interfaces | [decisions.md](decisions.md#open-question-compete-with-willow-or-collaborate) |
| Whether a browser-based configuration page is reachable for all users | [decisions.md](decisions.md#d11-mode-and-configuration-are-set-from-the-host-then-persisted) |
| Print tolerance against the force budget | [requirements.md](requirements.md) (HW-9) |
| Unverified firmware and host assumptions, resolved by bench measurement | [requirements.md](requirements.md) |

## Note

[README.md](../README.md) also carries a "Project status" section aimed at
contributors arriving at the repository. This file is the fuller internal view.
If they drift apart, the README is the one users see.

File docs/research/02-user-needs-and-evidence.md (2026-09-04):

# 02: User needs and evidence base

Captured 2026-09-04. See [README](README.md) for method and caveats.

**Question asked:** Who needs a low-force joystick and how many are there? What
does the literature say about force, fatigue, and tremor? Why is assistive
technology abandoned? How do these devices actually get mounted?

---

## 1. Who needs this, and how many

### Neuromuscular and neurological populations (US unless noted)

| Condition | Figure | Source |
| --- | --- | --- |
| SMA | ~9,400 living (Type I 1,610; II 3,944; III 3,875). Birth incidence 1:6,000 to 1:10,000; newborn screening 1:14,694 | [PMC5704427](https://www.ncbi.nlm.nih.gov/pmc/articles/PMC5704427/), [PMC11250364](https://pmc.ncbi.nlm.nih.gov/articles/PMC11250364/) |
| ALS | ~33,000 cases (2022), projected >36,000 by 2030. 2017 capture-recapture: 24,821 (7.7 per 100,000) | [CDC National ALS Registry](https://www.cdc.gov/als/php/abstracts-publications-reports/prevalence-2022-2030.html), [PMC9568617](https://www.ncbi.nlm.nih.gov/pmc/articles/PMC9568617/) |
| Duchenne / Becker MD | 1.38 per 10,000 males aged 5 to 24 (2010); 1.47 per 10,000 (2007) | MD STARnet, [PMC10031951](https://pmc.ncbi.nlm.nih.gov/articles/PMC10031951/) |
| Spinal cord injury | ~296,000 living (range 252,000 to 373,000); ~17,900 new per year. **C4 = 15.7% and C5 = 14.8% of all new injuries** | [NSCISC Facts and Figures](https://msktc.org/sites/default/files/Facts-and-Figures-2025-Eng-508.pdf) |
| Cerebral palsy | 1 in 345 children (ADDM 2010); >764,000 children and adults | [CDC ADDM](https://archive.cdc.gov/www_cdc_gov/ncbddd/cp/data.html) |
| Multiple sclerosis | ~1,000,000 (twice the prior estimate) | Wallin et al., *Neurology*, 2019 |
| Essential tremor | 6.4M adults at 2.6% prevalence; claims-diagnosed 1.1M (0.42%) | [Neurology 94(15) suppl](https://www.neurology.org/doi/10.1212/WNL.94.15_supplement.4458), [Tremor J. 2025](https://tremorjournal.org/articles/10.5334/tohm.1060) |
| Arthritis | 53.2M adults (21.2%), 2019 to 2021; **25.7M with activity limitation** | [CDC MMWR 72(41)](https://www.cdc.gov/mmwr/volumes/72/wr/mm7241a1.htm) |
| Arthrogryposis | **UNVERIFIED**, no reliable US prevalence retrieved | |

### The most on-point figure found

> **~250,000 people in the US cannot operate a powered wheelchair** due to
> motor, sensory, or cognitive impairment. The authors estimate **about half
> could drive if better input technology existed.**

Dicianno et al., *Joystick Control for Powered Mobility*, PM&R 2009,
[PMC2788504](https://pmc.ncbi.nlm.nih.gov/articles/PMC2788504/)

Note that this figure describes wheelchair *driving*, which the PRD scopes out
for regulatory reasons. It is cited as evidence that input force is a real and
quantified barrier, not as a target market for v1.

### Computer access specifically

- **Dexterity impairment among working-age computer users: 19% (24.4M) mild,
  5% (6.8M) severe.**
- **Computer use falls from 85% (no disability) to 80% (mild) to 63% (severe).**
  That 22-point gap is the addressable problem.
- Source: [PMC2788505](https://pmc.ncbi.nlm.nih.gov/articles/PMC2788505/)
- CDC DHDS: 28.7% of US adults report a functional disability; **mobility is the
  most common type at ~13%**
  ([CDC MMWR](https://www.cdc.gov/mmwr/preview/mmwrhtml/mm6429a2.htm))

### Gaming

- **46 million US gamers with disabilities** (AbleGamers estimate, carried in
  [ESA 2020 Essential Facts](https://www.theesa.com/wp-content/uploads/2021/03/Final-Edited-2020-ESA_Essential_facts.pdf))
- AbleGamers: people with disabilities are **51% more likely to be socially
  isolated**

### Global

- **2.5 billion people need at least one assistive product; ~1 billion are
  denied access.** Access ranges from 3% (low-income countries) to 90%
  (high-income). **Two-thirds pay out of pocket.** Need rises to 3.5 billion by
  2050.
- [WHO/UNICEF GReAT 2022](https://www.who.int/news/item/16-05-2022-almost-one-billion-children-and-adults-with-disabilities-and-older-persons-in-need-of-assistive-technology-denied-access--ac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)

---

## 2. Evidence on force and effort

### Force benchmarks

| Device class | Force |
| --- | --- |
| **Standard power-wheelchair joystick** | **200 to 250 gf** ([ATandMe](https://www.atandme.com/low-force-wheelchair-joysticks/)), 203 to 336 gf per NRRTS |
| mo-vis Micro Joystick | 8 gf, 3.3 mm throw (adapted version 5 gf) |
| ASL 130 MEC | 18 gf |
| Switch-It MICROPILOT | 10 gf, zero deflection |
| Switch-It MICROGUIDE | 40 gf |
| mo-vis Multi Joystick | 50 gf |
| **Xbox Adaptive Joystick** | **130 gf button actuation, 870 gf stick press.** 1/4-20 threaded mount, 106.2 g mass ([Xbox specs](https://www.xbox.com/en-US/accessories/controllers/xbox-adaptive-joystick)) |

Analog stick *deflection* force for mainstream gamepads: **UNVERIFIED**, no
vendor publishes it.

### Residual strength in target populations

Decostre, De Antonio, Servais & Hogrel, *Relationship Between Hand Strength and
Function in DMD and SMA*, J Neuromuscul Dis 2024, n=168
([PMC11307056](https://pmc.ncbi.nlm.nih.gov/articles/PMC11307056/)):

| Measure | DMD | SMA |
| --- | --- | --- |
| Mean handgrip | **4.08 kg** | **4.75 kg** |
| Mean key pinch | **1.40 kg** | **1.63 kg** (~20% of predicted) |
| Function retained down to | 11% predicted grip | 8% predicted grip |

**Implication:** a 200 to 250 gf (2.0 to 2.5 N) sustained demand is a
substantial and repeated fraction of residual pinch force for the weakest users.
A sub-10 gf target is roughly **1/25th** of that.

### Isometric vs displacement: the evidence is split, not settled

This is important. It is why the PRD makes response mode configurable (decision
D9) rather than committing to one architecture.

| Study | Finding |
| --- | --- |
| Cooper et al., *Analysis of position and isometric joysticks for powered wheelchair driving*, IEEE TBME 2000 ([PubMed 10916261](https://www.ncbi.nlm.nih.gov/pubmed/10916261)) | Isometric produced **fewer movement errors but longer reaction times** |
| Dicianno et al., *Joystick use for virtual EPW driving in individuals with tremor*, JRRD 2009;46(2):269-75 ([PubMed 19533540](https://pubmed.ncbi.nlm.nih.gov/19533540/)) | Isometric **preferred by participants with tremor** |
| Stewart, *Isometric Joystick: control by adolescents and young adults with cerebral palsy*, Aust Occup Ther J 1992 | Displacement was **superior for 4 of 5 CP subjects with prior displacement experience**. No difference for joystick-naive users |

Also relevant: isometric users **over-exert far beyond what is needed** without
training (PMC2788504).

### Tremor filtering: a documented negative result

- Low-pass filtering is inadequate. **MS tremor runs 3.5 to 5.0 Hz**, so a
  cutoff low enough to remove it introduces phase lag and deletes intentional
  commands.
- Adaptive notch (WFLC) is preferred in principle, but **Dicianno 2009 found
  WFLC did not improve performance** and may have damped intended motion.

**This is a real negative result, not an absence of evidence.** It is why the
PRD ships tremor filtering available but defaulted off, and user-defeatable
(decision D8).

### Fatigue and customization

| Finding | Source |
| --- | --- |
| Mouse and keyboard use draws only **~7% of wrist MVC**, yet **10 minutes at 15% MVC significantly degraded mouse tracking accuracy** | [PMC2788505](https://pmc.ncbi.nlm.nih.gov/articles/PMC2788505/) |
| Trewin & Pain: **error rates >10% for 14 of 20 users** with physical disabilities; **55% of drag tasks failed outright** | same |
| Pointer **gain adjustment gave a modest but statistically significant improvement (p<0.05, n=16)** | same |
| Automatic keyboard parameter configuration achieved a **96% reduction in repeated characters** | same |

**Two implications:** sustained low-level force is enough to impair fine motor
control even in unimpaired users, and *automatic* or guided configuration
outperforms manual tuning.

---

## 3. Assistive technology abandonment

This section drives the PRD's success metrics (Section 13).

| Study | Population | Non-use rate | Notes |
| --- | --- | --- | --- |
| **Phillips & Zhao 1993**, *Predictors of Assistive Technology Abandonment*, Assistive Technology 5(1):36-45, n=227 ([PubMed 10171664](https://pubmed.ncbi.nlm.nih.gov/10171664/)) | US | **29.3% completely abandoned** | **Mobility aids abandoned more than any other category.** Peaks in **year 1 and after year 5** |
| Federici & Borsci 2016 ([PubMed 26784731](https://pubmed.ncbi.nlm.nih.gov/26784731/)) | Italian NHS, n=749 | **17.9% non-use** | **40% of those never used the device at all** |
| Sugawara et al. 2018 ([PubMed 29334475](https://pubmed.ncbi.nlm.nih.gov/29334475/)) | São Paulo | **19.38% non-use** | Wheeled mobility had the *lowest* non-use; upper-limb orthoses the highest |

### The four significant predictors (Phillips & Zhao)

1. **User opinion not considered in selection**
2. Easy procurement
3. **Poor device performance**
4. Change in user needs

### Modern confirmation

A 2025 systematic review of AT for tetraplegia (34 studies, 366 participants,
[Assistive Technology](https://www.tandfonline.com/doi/full/10.1080/10400435.2025.2540119))
found that technically sound devices are abandoned when they give **poor UX,
operate slowly, are complex, cause high fatigue, or require excessive physical
effort**.

> The strongest documented predictor is that the user's opinion was not
> considered during selection. A project cannot retrofit that after shipping.
> This is why the PRD carries a process metric requiring feedback from real AT
> users before the v1 tag, rather than only product metrics.

---

## 4. What users complain about today

### Cost stacking

| Item | Price |
| --- | --- |
| Xbox Adaptive Controller base | **$99.99** |
| A *usable* XAC setup | **$270+** |
| Logitech Adaptive Gaming Kit | $99.99 |
| Individual switches | $22.55 to $549 |
| QuadStick FPS | from $549 |
| QuadStick Singleton | from $449 |
| Console + XAC setup | approaching **$1,000** |

Sources: [Can I Play That](https://caniplaythat.com/2020/09/24/xbox-adaptive-controller-review-xbox-pc/),
[Equal Entry](https://equalentry.com/does-the-xbox-adaptive-controller-deliver-on-the-hype/),
[QuadStick](https://www.quadstick.com/shop)

### Not usable standalone

The XAC ships with **8 buttons total**, and only **2 of 7 buttons plus the
d-pad** are usable without buying external hardware. Reviewers describe it as
designed for the most severely disabled while **leaving moderate-impairment
users unserved**.

### Configuration burden

Reviewers report **hours of manual remapping and emulator digging** before basic
function. Clinical drive-control tuning is therapist-mediated.

### Provisioning throughput

SpecialEffect: initial contact **2 to 4 weeks**, then a **1 to 3 month waiting
list** for a visit. **British Isles only.** The loan kit is recalled and
reissued. ([SpecialEffect FAQs](https://specialeffect.org.uk/faqs))

### Affordability

Two-thirds of AT users worldwide pay out of pocket (WHO 2022).

### UNVERIFIED

Drift, dead zone, and repairability complaints are widely discussed in community
forums, but primary community threads could not be retrieved (Reddit API
blocked). Wheelchair breakdown and repair statistics also **UNVERIFIED**.

---

## 5. Mounting and physical context

### De facto standards

| Standard | Dimensions | Notes |
| --- | --- | --- |
| **AMPS 4-hole pattern** | **30 mm x 38 mm** (1.181" x 1.496") | The industry standard, used by RAM Mounts. 2-hole variant is the diagonal at ~48.41 mm ([Bulletpoint](https://www.bulletpointmountingsolutions.com/pages/amps-standard-patterns-explained)) |
| **RAM ball sizes** | B = 1", C = 1.5", D = 2.25" | **The 1" B ball is the practical wheelchair and AT size** ([RAM Mounts](https://rammount.com/collections/amps-bases)) |
| **1/4"-20 UNC** | | **The strongest cross-ecosystem interface.** The Xbox Adaptive Joystick uses it; Rehadapt ships a Tube Ø10x50 with 1/4"-UNC thread |
| Special-controls hardware | 6 mm rod + half clamp | mo-vis ships a Q2M Rod D6 x 50 mm and D6 half clamp |

### The bridge to the clinical ecosystem

The **Rehadapt Universal Device Socket bridges to VESA 75/100, Daessy, Armon
Edero, and LC-Tech** ([Rehadapt](https://rehadapt.com/sockets/system-bridges/)).
Supporting UDS or VESA therefore reaches the whole clinical mount ecosystem
through one interface.

Daessy uses modular quick-release bases plus device adapter plates. Exact tube
OD **UNVERIFIED**.

### Real use contexts

Wheelchair armrest, tray, swing-away arm, chin or lip mount, plus **desk/table
and in-bed use**.

> Mounting must be repositionable by a caregiver in seconds, not bolted once.

---

## Top 6 requirements this evidence implies

These fed directly into the PRD.

1. **Actuation under 10 gf, with force and throw both specified and published.**
   Level with mo-vis Micro (8 gf) and Switch-It MICROPILOT (10 gf), and ~25x
   below the 200 to 250 gf clinical standard. Defensible against measured
   residual pinch forces of 1.4 to 1.6 kg in DMD and SMA.

2. **Ship both displacement and isometric-like modes, selectable in software.**
   The literature is genuinely split. Configurability, not an architecture
   choice, is the evidence-backed answer.

3. **User-facing customization with no clinician required**: deadzone, gain
   curve, per-axis scaling, tremor filtering, profiles. Gain tuning shows
   measured significant benefit, and configuration burden is a top complaint.
   Guided or automatic calibration beats manual tuning (96% error reduction
   precedent).

4. **Tremor handling must be adaptive and defeatable.** Fixed low-pass fails at
   MS tremor frequencies of 3.5 to 5.0 Hz, and WFLC did not help in the one
   controlled trial. Expose it, default it off, let users A/B it.

5. **Mount to the existing ecosystem out of the box**: 1/4"-20 insert + AMPS
   30x38 mm pattern, plus a 1" RAM ball adapter. That combination reaches RAM,
   Rehadapt UDS (and through it VESA 75/100 and Daessy), and the Xbox Adaptive
   Joystick convention, at negligible BOM cost.

6. **Design against the abandonment predictors directly**: involve users in
   selection, price far below the $270 to $549 adaptive band, and make it
   self-repairable. Open hardware plus published spares and firmware answers
   "changing needs" and repairability in a way no proprietary vendor currently
   does.

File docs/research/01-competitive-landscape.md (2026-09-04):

# 01: Competitive landscape

Captured 2026-09-04. See [README](README.md) for method and caveats.

**Question asked:** What adaptive, clinical, and consumer joysticks already
exist, what force do they actually require, what do they cost, and what is not
served today?

---

## Headline finding

**Sub-10 gram actuation is already claimed by shipping products.** Three beat
10 gf: mo-vis Micro (8 to 8.5 gf), ASL 128 Molecule (8 gf), and Celtic Magic
Feather (adjustable to 5 gf).

None of them is open source. None is cheap. Only one is a native USB HID gaming
device.

> **The gap is not force. It is force + USB HID gamepad + open source +
> a published price under ~$200.**

---

## Product table

| Product | Vendor | Price USD | Force to full deflection | Throw | Connectivity | Hosts | Open? |
| --- | --- | --- | --- | --- | --- | --- | --- |
| **mo-vis Micro Joystick HID** (P025-61) | mo-vis (BE) | Dealer-gated, no public price | **8.5 gf** | **3.3 mm** | USB composite HID (mouse + kbd + **gamepad**) | Win/macOS/Android/iOS/Xbox/XAC | No |
| mo-vis Multi Joystick HID (P025-62) | mo-vis | Dealer | 50 gf | 8 mm | Same | Same | No |
| **Celtic Magic Feather** CM/FJ | Celtic Magic (UK) | **£420 (~$530)** | **5 / 10 / 16 / 20 gf** user-selectable (1 to 4 magnets) | ±6° | USB, 2x 3.5 mm | PC, XAC | No (all rights reserved) |
| Celtic Magic Dangle | Celtic Magic | £190 to £260 | 10 gf | Not published | USB + 3.5 mm | PC, XAC | No |
| **ASL 128 Molecule** | ASL | Dealer-only, UNVERIFIED | **8 gf** | **3 mm** | R-net / Q-Logic / LiNX + built-in BT mouse mode | Wheelchair-mediated | No |
| ASL 130 MEC | ASL | Dealer-only | 18 gf | 13 mm | As above | As above | No |
| Permobil / HMC Mini Joystick | Permobil | Dealer-only | 13 gf | 3 mm | Chair bus + BT module | As above | No |
| Switch-It MicroPilot | Sunrise | ~$3,295 start (reseller) | 10 to 50 gf adjustable, **isometric** | **0 mm** | Chair bus | As above | No, **discontinued** |
| Switch-It MicroGuide | Sunrise | Dealer | 25 gf (NRRTS) / ~40 gf (ATandMe) | 6 mm | Chair bus | As above | No |
| Stealth Precision Mini Proportional | Stealth i-Drive | Dealer | 43 gf | 7 to 14.4 mm | i-Drive CPU | As above | No |
| *Standard wheelchair joystick* | (reference) | | **203 to 336 gf** | 19.5 to 28 mm | | | |
| **Willow Joystick** | Makers Making Change | **~$180 BOM (~$135 at volume)** | **25 gf** | ±7.5° / ±5 mm | USB HID mouse + gamepad, BLE | PC/Mac/Android/iOS/XAC | **Yes.** CERN-OHL-W-2.0 + GPL-3.0, OSHWA CA000062, Hall-effect (TLV493D) |
| MMC Spruce / Birch / Oak | Makers Making Change | DIY | 75 / 115 / 525 gf | Not published | 3.5 mm TRRS, USB | XAC, PC | Yes |
| LipSync (Gaming) | MMC / Neil Squire | ~$250 built, ~$325 BOM | 50 gf | Not published | USB HID + BT | PC, XAC | Yes |
| **Xbox Adaptive Joystick** | Microsoft | **$29.99** | **Stick force NOT published** (buttons 130 gf) | Not published | USB-C wired only | Xbox + **Windows 11 x64 only** | No |
| Xbox Adaptive Controller | Microsoft | $99.99 | n/a (hub) | n/a | 19x 3.5 mm, 2x USB | Xbox, Windows | No |
| Logitech G Adaptive Gaming Kit | Logitech | $99 | Buttons 56 to 59 gf | n/a | 3.5 mm into XAC | Requires XAC | No |
| Hori Flex | Hori | $249 | Not published | Not published | USB-A | Switch (docked only), Windows | No |
| **QuadStick FPS / Singleton** | QuadStick | **$549 / $449** (+$105 to $249 mount) | 25 gf light springs / 60 to 70 gf strong | Not published | USB HID + optional BT | PS / Switch / PC / Mac / Android | Partial (3D files only) |
| Pretorian Optima | Pretorian (UK) | $295 / £192 ex-VAT | **0.5 N ≈ 51 gf** | Not published | USB / PS2 + 3.5 mm | PC/Mac/Chromebook/iOS, XAC mode | No |
| Pretorian n-ABLER | Pretorian | £275 ex-VAT | Not published ("light touch") | Not published | USB + 3.5 mm | PC/Mac/iPad/Android | No |
| GlassOuse PRO / V1.4 / Link | GlassOuse | $799 / $599 / $499 | Not published (head-tilt) | n/a | BT 4.0 + 3.5 mm | Win/Mac/**Linux**/iOS/Android | No |
| TetraMouse TMXA2 / TMXS | TetraMouse | $449 / $349 | Not published (full manual checked) | Not published | USB HID mouse only | Windows, Mac | No |
| Penny+Giles JC2000 | Curtiss-Wright | OEM only | 1 to 3 N breakout / 2 to 4.5 N full (~102 to 204 gf) | ±20° | OEM analog, **not USB** | Component | No. **Hall, contactless**, 15M operations |
| GuliKit / 8BitDo Hall and TMR modules | Various | $18 to $60 | **Never published** | Not published | Replacement modules | Consoles | No |
| ALPS RKJXV (incumbent potentiometer) | Alps Alpine | $3 to $6 | 14 ±10 mN·m torque | 23° | Analog | Component | No |

---

## The force spectrum

- The field spans roughly **130x**: from 5 gf (Feather minimum, and a mo-vis
  5 gf adapted Micro, P002-55) up to 650 gf (mo-vis All-Around Heavy Duty).
- **Standard wheelchair joystick: 203 to 336 gf.**
- Standard gaming thumbstick: **~65 to 150 gf equivalent**, community-measured,
  **UNVERIFIED**.
- **Sub-10 gf is occupied.** mo-vis Micro (8.5 gf / 3.3 mm) and ASL Molecule
  (8 gf / 3 mm) are the displacement-based floor. Feather is adjustable to 5 gf.
  mo-vis ships a 5 gf adapted Micro but warns it requires "special attention to
  mounting, shielding and testing."

### Two architectures

| | Displacement | Isometric / zero-throw |
| --- | --- | --- |
| Example | mo-vis Micro, 8 gf @ 3.3 mm | Switch-It MicroPilot, 10 to 50 gf @ 0 mm |
| Also | ASL Molecule, 8 gf @ 3 mm | ASL 136 Micro Mini |

See [document 02](02-user-needs-and-evidence.md) for the clinical evidence on
which performs better. It is genuinely split.

### There is no standardized measurement protocol

Vendors and third parties disagree on the same products:

| Product | Vendor claim | Third party |
| --- | --- | --- |
| Switch-It MicroGuide | 25 gf (NRRTS chart) | ~40 gf (ATandMe) |
| ASL 130 MEC throw | 9 mm | 13 mm |

**Gaming vendors publish nothing at all.** Microsoft, Sony, Nintendo, GuliKit,
8BitDo, Hori, and Logitech publish zero stick actuation force. Microsoft
publishes button force in gf for the Xbox Adaptive Joystick but not stick force.

> Publishing a documented, repeatable force-test method is itself a
> differentiator. This became PRD requirement HW-2.

### Counter-signal: adjustable beats minimum

Celtic Magic states directly that *"an extremely light force stick can be just
too light and in practice be harder to use."* That is why the Feather ships a
4-step 5/10/16/20 gf magnet adjustment rather than simply going as light as
possible.

Combined with the mo-vis warning about its 5 gf variant, two independent vendors
at the low-force frontier report that too-light is a real failure mode. This
directly informed the proposed amendment to design principle 1 in the PRD.

---

## Price spectrum and the gap

| Band | Products | What it misses |
| --- | --- | --- |
| **$30 to $100** mainstream adaptive | Xbox Adaptive Joystick $29.99, XAC $99.99, Logitech kit $99 | No published force spec, host-locked, companion-not-controller |
| **$180 to $250** open DIY | Willow (~$180 BOM), LipSync | Open source, but 25 gf floor and maker-network distribution only |
| **$300 to $800** AT computer access | Optima $295, TetraMouse $449, QuadStick $449 to $549, Feather ~$530, GlassOuse $499 to $799 | 20 to 51 gf except Feather; mostly mouse emulation |
| **$3,000+** dealer-gated clinical | ASL, Permobil, Switch-It | Sub-10 gf exists here, unbuyable without a chair, an ATP, and insurance authorization |

> **The empty cell: a purchasable, priced, open-source, sub-10 gf USB HID
> gamepad in the $150 to $250 band. Nothing occupies it.**

---

## What is not served today

1. **Sub-10 gf without a wheelchair.** ASL, Permobil, and Switch-It sub-10 gf
   devices ride proprietary R-net / Q-Logic / LiNX buses. mo-vis' USB on the
   *drive* Micro is configuration-only, not an input path.

2. **Native gamepad rather than mouse emulation.** AT joysticks are
   overwhelmingly mouse devices. Optima's "gaming mode" is XAC-only. n-ABLER has
   no gamepad output at all. NRRTS documents that R-Net Bluetooth mouse
   emulation introduced *"an unexpected lag to the pointer movements"* that speed
   settings did not fix.

3. **Host lock-in.** The Xbox Adaptive Joystick is Xbox + Windows 11 x64 only,
   with no Mac, Linux, iOS, or Android. Hori Flex is docked-Switch only.
   **Linux is essentially unclaimed**: only GlassOuse, Origin, and BJOY list it.

4. **Availability.** QuadStick sells in weekly Monday drops and was fully sold
   out at capture. mo-vis and Celtic Magic's US reseller are quote-only. Ability
   Drive is defunct. Traxsys exited AT. MicroPilot is discontinued.

5. **No commercial open source at any force point.** QuadStick's repository
   holds 3D files only. Celtic Magic reserves all rights. **Zero commercial AT
   joystick ships schematics or firmware.**

6. **Drift and wear.** Potentiometer-based AT joysticks degrade in 1 to 2 years.
   Even the magnetic Feather's own manual documents the stick *"creeping on its
   own"* and requiring recalibration. Contactless sensing plus documented
   calibration is a defensible claim.

7. **Cost and insurance.** A working XAC setup runs *"upwards of $270"*.
   QuadStick runs ~$600 plus a $105 to $229 mount. Gaming devices are rarely
   funded as medically necessary (see
   [document 04](04-funding-and-compliance.md)).

8. **Fatigue is the real complaint, not capability.** A gamer with cerebral
   palsy reports that 30 minutes of play leaves them *"exhausted for at least a
   few hours."*

---

## Unverified in this document

- ASL, Permobil, and Stealth **prices**: no vendor publishes MSRP
- 8BitDo Lite SE price and Hall-effect claim: official page returned 403
- Inclusive Versatility v5 Microlite "5 to 10 gf / 5 mm": sourced once, page
  would not re-fetch
- Evil Controllers $150 to $500
- Community-measured mainstream thumbstick force
- Freedom2Move: site serves a placeholder, could not verify it ships a product

---

## Sources

[NRRTS mini-joystick comparison chart](https://nrrts.org/wp-content/uploads/2019/09/Mini-Joystick-Comparison-Chart-Final.pdf)
(the best cross-vendor force and throw table found; extracted and verified
directly) ·
[Quantum proportional drive controls](https://www.quantumrehab.com/quantum-rehab-clinicians/pdf/quantum-proportional-drive-controls.pdf) ·
[mo-vis HID Joystick](https://www.mo-vis.com/products/other-assistive-devices/hid-joystick) ·
[mo-vis Micro Joystick](https://www.mo-vis.com/products/special-controls/micro-joystick) ·
[Celtic Magic Feather](https://www.celticmagic.org/feather) ·
[Celtic Magic buy options](https://www.celticmagic.org/feather-buy-options) ·
[Willow Joystick](https://github.com/makersmakingchange/Willow-Joystick) ·
[OpenAT Joysticks](https://github.com/makersmakingchange/OpenAT-Joysticks) ·
[Xbox Adaptive Joystick specs](https://www.xbox.com/en-US/accessories/controllers/xbox-adaptive-joystick) ·
[QuadStick shop](https://www.quadstick.com/shop) ·
[Pretorian Optima](https://www.pretorianuk.com/optima-joystick) ·
[Switch-It MicroPilot](https://www.sunrisemedical.com/power-wheelchairs/switch-it-electronics/joysticks/micropilot) ·
[ATandMe low-force joysticks](https://www.atandme.com/low-force-wheelchair-joysticks/) ·
[SpecialEffect GameAccess](https://gameaccess.info/low-force-joysticks-and-switches/) ·
[Access-Ability XAJ review](https://access-ability.uk/2025/03/25/xbox-adaptive-joystick-accessibility-review/) ·
[Can I Play That? XAC review](https://caniplaythat.com/2020/09/24/xbox-adaptive-controller-review-xbox-pc/) ·
[NRRTS R-Net Bluetooth lag](https://nrrts.org/wp-content/uploads/2019/06/DIRECTIONS_2016.3_RCS.pdf) ·
[Kotaku, cerebral palsy gaming fatigue](https://kotaku.com/the-unpredictable-challenges-of-gaming-with-cerebral-pa-1841668450)

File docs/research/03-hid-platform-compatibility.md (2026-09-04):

# 03: HID, platform, and hardware constraints

Captured 2026-09-04. See [README](README.md) for method and caveats.

**Question asked:** What HID class should the device present? What is actually
required for console support? What are the ESP32-S3's real constraints? What
does espp already provide? What latency is achievable?

---

## Local baseline

Verified in the repository at capture: ESP-IDF 6.0.2, espp components pinned
1.2.0, `espp/usb_device` 3.0.0 pulling `espressif/esp_tinyusb` and
`espressif/tinyusb` 0.21.0. `sdkconfig.defaults` already sets
`CONFIG_TINYUSB_HID_COUNT=1` and `CONFIG_TINYUSB_CDC_ENABLED=y`, but leaves
`CONFIG_FREERTOS_HZ=1000` and 240 MHz **commented out**. `main.cpp` is a sensor
bring-up demo on the espp `qtpy` BSP at 400 kHz, address 0x35.

---

## 1. HID device class choice

### What works driverless

A generic HID **gamepad (usage 0x05)** or **joystick (0x04)** is driverless
everywhere:

| Platform | Mechanism |
| --- | --- |
| Windows | HID class driver. Appears in `joy.cpl`, DirectInput, `RawGameController` |
| macOS | IOKit HID |
| Linux / ChromeOS | evdev / joydev |
| Android | `SOURCE_GAMEPAD` |

### The two platform traps

**Windows never exposes a generic HID device via XInput.** XInput is reserved
for devices carrying Microsoft's XUSB descriptor set
([learn.microsoft.com](https://learn.microsoft.com/en-us/windows/win32/xinput/directinput-and-xusb-devices)).
Many modern titles are XInput-only and **will not see the stick at all**.

**macOS and iOS do not accept a generic gamepad into GameController.framework.**
Apple's stack gates on MFi, Xbox, DualSense, and other known PnP IDs. Devices
pair but produce no `GCController`, with an unresolved Apple bug on file
([developer.apple.com/forums/thread/741756](https://developer.apple.com/forums/thread/741756)).

> HID **mouse and keyboard** on iPadOS *is* fully supported via the
> AssistiveTouch pointer. **On iPad, mouse mode is the only working mode.**

### Workarounds for the XInput gap

| Option | Status |
| --- | --- |
| **Steam Input** | **The practical answer.** Reads generic HID and injects a virtual Xbox pad into any Steam-launched game ([partner.steamgames.com](https://partner.steamgames.com/doc/features/steam_controller/steam_input_gamepad_emulation_bestpractices)) |
| ViGEmBus | **Archived November 2023** |
| x360ce, DS4Windows | Per-game shims, fragile |
| True Xbox emulation | Requires the proprietary descriptor plus auth silicon. **Not a legitimate path** |

### Composite devices

Mouse + gamepad on separate report IDs works on Windows, Linux, and macOS, and
is exactly what the AT field already does: Makers Making Change's OpenAT
joysticks (Cedar, Redwood, Willow, Forest Hub) all ship "USB HID Mouse or USB
HID Gamepad" with a **physical mode-cycle switch**
([OpenAT-Joysticks](https://github.com/makersmakingchange/OpenAT-Joysticks)).

**Risk:** Apple forum reports suggest exotic or composite descriptors can make
iOS ignore the device entirely. This needs specific bench verification, since
iPad is the platform where mouse mode is the only option.

### Recommendation adopted

Single USB HID interface exposing **two report IDs, gamepad + mouse**, with a
host-independent mode selector that changes which report is sent, **not** the
descriptor, so the host never re-enumerates. Ship as a DirectInput-style gamepad
first, document Steam Input as the XInput answer, treat mouse mode as the
guaranteed-everywhere fallback.

---

## 2. Console compatibility

### Direct connection is closed on all three

| Console | Barrier |
| --- | --- |
| **Xbox One / Series** | Since November 2023 Microsoft blocks unlicensed accessories with error **`0x82d60002`** after a two-week grace period ([Windows Central](https://www.windowscentral.com/gaming/xbox/xboxs-new-policy-say-goodbye-to-unofficial-accessories-after-november)). Requires "Designed for Xbox" licensing and an auth IC |
| **PS5** | Requires DualSense cryptographic auth for PS5-native titles. **PS4** mode needs uploaded encryption keys or a passthrough auth device. GP2040-CE documents this and refuses to distribute keys ([gp2040-ce.info FAQ](https://gp2040-ce.info/faq/faq-console-compatibility/)) |
| **Nintendo Switch** | Does **not** accept generic USB HID. Requires a proprietary handshake (`80`-prefixed commands, baud negotiation, USB-lock) ([dekuNukem notes](https://github.com/dekuNukem/Nintendo_Switch_Reverse_Engineering/blob/master/USB-HID-Notes.md)). Switch 2 auth: **UNVERIFIED** |

Brook, Titan Two, and CronusMax are gray-area passthrough devices with terms-of-
service and ban risk.

### The XAC is the legitimate exemption

Microsoft confirmed the accessory block has **"no impact to players using the
Xbox Adaptive Controller regardless of the peripherals plugged into its USB and
3.5mm ports"**
([Can I Play That](https://caniplaythat.com/2023/10/30/xbox-unlicensed-accessory-block-sparks-adaptive-controller-concerns/)).
The console only ever sees the licensed XAC.

### XAC USB-A is proven for DIY HID joysticks

The `dinput_pluggable` project documents the exact mapping
([dinput_pluggable](https://github.com/controllercustom/dinput_pluggable),
[Arduino forum](https://forum.arduino.cc/t/joystick-for-xbox-adaptive-controller/1325039)):

| Descriptor usage | XAC target |
| --- | --- |
| X, Y | Left stick |
| Z, RZ | Right stick |
| Hat switch | D-pad |

**Requires XAC firmware June 2024 or newer.** Warning: the default button
mapping for external USB joystick buttons is reported as unexpected.

### XAC 3.5 mm ports

- **19 digital jacks**: TRS, tip-to-sleeve momentary closure against an internal
  1.8 V pull-up. Trivially driven by a GPIO or optocoupler. Digital only.
- **Analog ports X1, X2, LT, RT**: TRRS, potentiometer-style input.
  **Tip = axis 1, Ring1 = axis 2, Ring2 = GND, Sleeve = 3.3 V reference**
  ([Adafruit XAC standards](https://learn.adafruit.com/diy-adaptive-game-controllers/xac-standards)).
  This is what OpenAT's Oak and Spruce joysticks use.

### Xbox Adaptive Joystick (2025)

~$30, wired, connects to Xbox, Windows 11, or the XAC. It is itself licensed. It
does **not** change what the XAC's ports accept
([Pure Xbox](https://www.purexbox.com/news/2025/03/xboxs-new-adaptive-joystick-is-officially-now-available-to-buy/)).

### Recommendation adopted

Console support routes **through the XAC USB-A port**. Match the
`dinput_pluggable` descriptor shape (X/Y/Z/RZ + hat) so the stick maps to the
left thumbstick with no licensing. Analog TRRS output to X1/X2 needs a DAC and a
hardware variant: deferred to v2. Direct PS4/PS5/Switch/Xbox is explicitly out
of scope.

---

## 3. ESP32-S3 specifics

### Bluetooth: BLE only

ESP-IDF states plainly: **"ESP-Bluedroid for ESP32-S3 supports Bluetooth LE
only. Classic Bluetooth is not supported"**
([docs.espressif.com](https://docs.espressif.com/projects/esp-idf/en/stable/esp32s3/api-guides/ble/overview.html)).
Only the original ESP32 is dual-mode. **Bluetooth Classic HID is off the table
entirely.**

BLE HID (HOGP) works via Bluedroid `ble_hid_device_demo`. NimBLE has no official
Espressif HID example ([esp-idf#15220](https://github.com/espressif/esp-idf/issues/15220)),
though espp ships a real `hid_service` NimBLE GATT component.

**Host acceptance mirrors USB:** Android and Windows accept generic BLE HID
gamepads; **iOS and macOS reject them** unless the PnP ID matches a known
controller. BLE therefore buys no platform that USB does not already provide.

### USB PHY: the eFuse question

The ESP32-S3 has one full-speed (12 Mbit/s) USB-OTG plus USB-Serial-JTAG,
sharing GPIO19/20. The ESP-IDF console documentation says the internal PHY
defaults to USB_SERIAL_JTAG and can be **"permanently"** switched via the
`USB_PHY_SEL` eFuse
([usb-otg-console](https://docs.espressif.com/projects/esp-idf/en/stable/esp32s3/api-guides/usb-otg-console.html)).

That wording concerns the **ROM/console** case. In practice `esp_tinyusb`
re-routes the internal PHY to OTG at runtime, which is why stock S3 boards run
TinyUSB over the built-in USB-C with no eFuse burn.

> **Treat "no eFuse burn required" as high confidence but UNVERIFIED. Bench-
> verify on the QT Py before committing hardware.** If wrong, every unit needs an
> irreversible eFuse burn. Open item, to be resolved before a hardware commit.

### Consequences either way

- Once TinyUSB owns the port, the USB-Serial-JTAG console is gone.
- `CONFIG_ESP_CONSOLE_USB_CDC` (ROM CDC) is **incompatible** with TinyUSB.
- Reflashing typically needs the BOOT+RESET combo
  ([esptool troubleshooting](https://docs.espressif.com/projects/esptool/en/latest/esp32s3/troubleshooting.html)).

### Known rough edges

- **Sustained 1 kHz HID on ESP32-S3 + TinyUSB: UNVERIFIED.** No benchmark found.
- **Endpoint stalls after consecutive HID reports larger than 64 bytes**
  ([esp-idf#9992](https://github.com/espressif/esp-idf/issues/9992)). Keep
  reports small.

### Recommendation adopted

USB-only. BLE explicitly deferred, and never a path to iOS gamepad support. Add
a CDC-ACM interface alongside HID in the same TinyUSB composite for logging and
an optional config CLI, plus a UART console on spare GPIOs for bring-up. Set
`CONFIG_FREERTOS_HZ=1000` and 240 MHz in `sdkconfig.defaults`.

---

## 4. espp capabilities and gaps

### What exists

**`hid-rp`** provides
`espp::GamepadInputReport<BUTTON_COUNT=15, JOYSTICK_TYPE=uint16_t, ...>` with
**X/Y left stick, Z/RZ right stick, 2 triggers, 4-bit hat, N buttons**, plus
`set_left_joystick(float,float)` in [-1,1], `set_button`, `set_hat`,
`get_report()`, and `static get_descriptor()`. It also ships Xbox, Switch Pro,
DualShock 4, and DualSense report and descriptor sets
([hid-rp-gamepad.hpp](https://github.com/esp-cpp/espp/blob/main/components/hid-rp/include/hid-rp-gamepad.hpp)).

> **This layout is a direct match for the XAC mapping in section 2.**

Caveat: `get_descriptor()` returns a fragment the caller must wrap in
`usage_page<generic_desktop>` / `usage(GAMEPAD)` / `collection::application`.

**`joystick`** provides `espp::Joystick` with
`Config{x_calibration, y_calibration (FloatRangeMapper::Config), type
RECTANGULAR|CIRCULAR, center_deadzone_radius, range_deadzone, get_values_fn}`,
plus `update()`, `x()/y()/position()/raw()`, and `set_calibration()`.
`FloatRangeMapper::Config` carries `center, center_deadband, minimum, maximum,
range_deadband, invert_output`.

> **There is no `calibrate()` routine, and mapping is linear only.**

**`usb_device`** wraps `esp_tinyusb`.
`HidFunction{interface_name, std::vector<uint8_t> report_descriptor,
has_out_endpoint=false, poll_interval_ms=10}` where `poll_interval_ms` becomes
bInterval. Also `write_hid_report(report_id, span, ec)` and `is_hid_ready()`.
CDC and vendor/WebUSB functions live in the same `Config`, so the composite
device in section 3 is a configuration change, not new code.

> **`poll_interval_ms` defaults to 10, which is only 100 Hz.** This must be
> overridden explicitly. Recorded as PRD requirement OUT-5.

Also available: `math` (`RangeMapper`, `bezier.hpp`, `vector2d`), `filters`
(lowpass, butterworth, biquad, kalman), `nvs`, and `hid_service` (BLE HOGP).

### Gaps Omega Stick must write itself

- **The glue from sensor to `Joystick` to `GamepadInputReport` to
  `write_hid_report`. No such example exists anywhere in espp.**
- NVS calibration schema
- Boot and idle auto-centering
- Exponential and response-curve shaping (`RangeMapper` is linear;
  `bezier.hpp` is the building block)
- The gamepad/mouse mode switch

---

## 5. Sensor and latency budget

### TMAG5273 characteristics

| Property | Value |
| --- | --- |
| ADC | **12-bit**, 3-axis |
| Sample rate | **20 kSPS single-axis / 10 kSPS 3-axis** at CONV_AVG=1x |
| I2C | up to 1 MHz |
| Current | 2.3 mA active |
| Ranges | **x1 part ±40 / ±80 mT; x2 part ±133 / ±266 mT** |
| Sensitivity drift | **5% typical** over -40 to 125 °C |

Source: [ti.com/product/TMAG5273](https://www.ti.com/product/TMAG5273)

Averaging trades rate for noise: 4x ≈ 3.1 kSPS 3-axis, 32x ≈ 0.4 kSPS.

**RMS noise figures: UNVERIFIED**, not extractable from the PDF this session.
Open item requiring bench measurement.

At ±40 mT, one LSB ≈ **19.5 µT** (computed). The x1 part at ±40 mT is the right
choice for a small magnet over a few millimeters.

### Drift requires runtime re-centering

The on-chip offset registers are a **static user trim, not drift tracking**.
With 5% typical sensitivity drift across temperature, **runtime re-centering is
required, not optional.** The on-chip temperature sensor plus MAG_TEMPCO
compensates NdFeB and ceramic magnets.

### I2C throughput (computed, 400 kHz)

| Read | Time | Bus-limited rate |
| --- | --- | --- |
| XY-only, 4 bytes | ≈158 µs | ≈6.3 kHz |
| XYZ, 6 bytes | ≈202 µs | ≈4.9 kHz |

Sensor + I2C + filtering is comfortably **under 0.5 ms**. **The sensor is never
the bottleneck.**

The device has an **INT pin** usable as data-ready, and 1-byte read modes that
skip the register-address write.

### End-to-end latency (computed)

| bInterval | End-to-end |
| --- | --- |
| 1 ms | **2 to 3 ms** |
| 4 ms | 4 to 6 ms |
| 8 ms | 6 to 9 ms |

Human thresholds are far coarser (~67 ms for twitch genres,
[Input lag](https://en.wikipedia.org/wiki/Input_lag)). Commonly cited Xbox pad
125 Hz and DualSense 250 Hz figures are **UNVERIFIED**.

### Findings in the local driver

Reviewed `components/tmag5273/include/tmag5273.hpp`:

- `read_raw()` already does a **6-byte burst** from `X_MSB_RESULT`, so the fast
  path exists, **but there is no XY-only 4-byte read**.
- `INT_CONFIG_1`, `MAG_GAIN_CONFIG`, and `MAG_OFFSET_CONFIG_1/2` are **declared
  and never used**, so there is no data-ready interrupt and no on-chip trim.
- **Defect:** `range_xy_mT()` returns `266.0f` unconditionally with a comment
  acknowledging it, and `convert_raw_to_mT` consumes it as the LOW full-scale
  while doubling for HIGH. `read_z()` passes `z_range_` correctly but
  `convert_raw_to_mT` always reaches for the XY constant, leaving `range_z_mT()`
  dead. Full analysis in the PRD's known-defects section.

### Recommendation adopted

x1 part at ±40 mT, **CONV_AVG 4x** (≈3.1 kSPS, real noise reduction, still ~10x
faster than needed), continuous mode, **XY 4-byte burst polled at 1 kHz from a
dedicated pinned task**, decimated to a **1 ms bInterval HID report sent on
change**. Fix the range defect and **work the joystick math in raw counts** so
the mT bug cannot affect feel. Wire the INT pin as data-ready if the board
exposes it. Do runtime re-centering (boot capture plus slow idle drift
correction) to absorb thermal sensitivity drift.

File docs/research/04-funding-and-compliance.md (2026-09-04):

# 04: Funding and compliance

Captured 2026-09-04. See [README](README.md) for method and caveats.

**Not legal advice.** This records what primary sources say. Inferences are
marked UNVERIFIED.

**Question asked:** How does this get funded? What compliance obligations attach
to selling it? What accessibility standards will buyers cite? Does open sourcing
conflict with any of it?

**Scope note:** medical-device regulatory analysis was removed from this
document. The project's position is simply that Omega Stick is a general-purpose
input peripheral and makes no medical claims. See [compliance.md](../compliance.md).

---

## 1. Reimbursement and funding (US)

### Medicare will not fund general computer access

DME must be durable, home-use, and **primarily and customarily used to serve a
medical purpose**. General-purpose computing fails this test
([Center for Medicare Advocacy](https://medicareadvocacy.org/medicare-info/medicare-part-b/durable-medical-equipment/)).

### The one viable code

**E2599, accessory for a speech generating device, not otherwise classified.**

Coverage exists when the base SGD is covered and each accessory's medical
necessity is documented in the SLP's formal evaluation. Access devices explicitly
named include **joysticks, switches, optical head pointers, wheelchair
integration devices, and scanning devices**
([CMS SGD article](https://www.cms.gov/medicare-coverage-database/view/article.aspx?articleId=52469),
[ASHA SGD policy](https://www.asha.org/practice/reimbursement/medicare/sgd_policy/)).
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

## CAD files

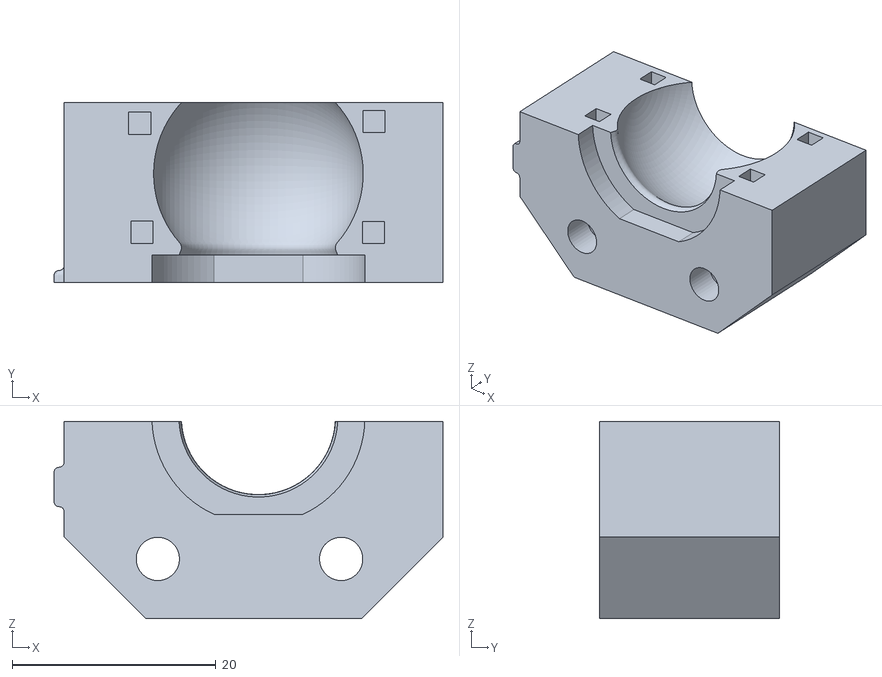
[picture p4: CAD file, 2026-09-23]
models/omega_socket1.stl
38.2 x 17.7 x 19.3

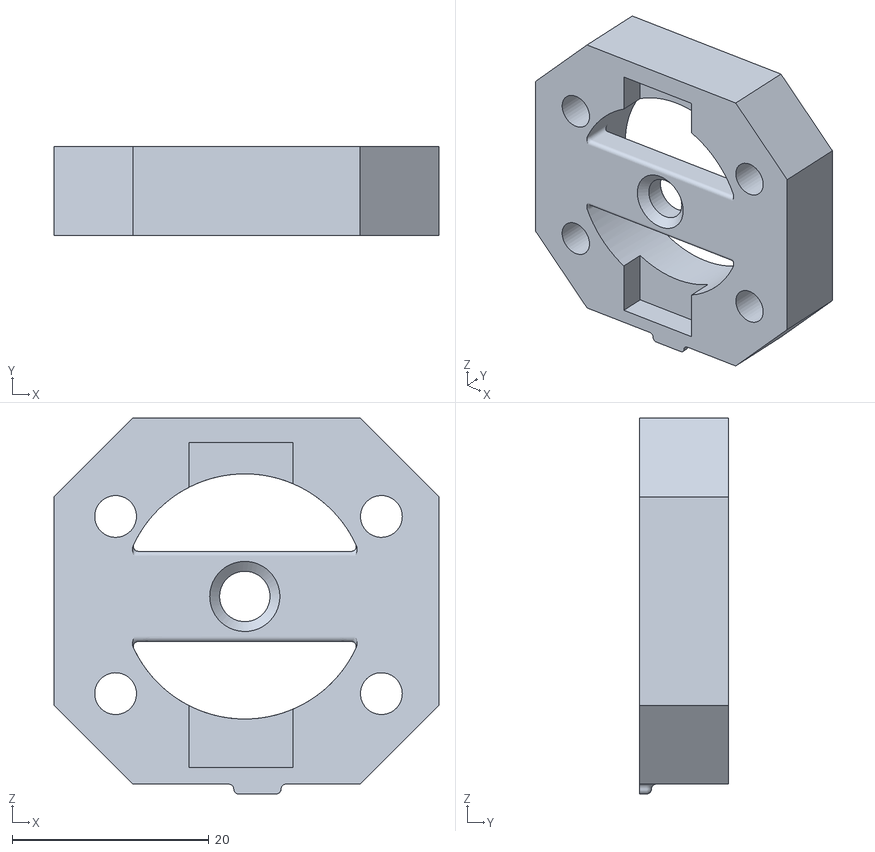
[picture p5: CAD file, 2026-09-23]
models/omega_mag_holder.stl
39.1 x 9.00 x 38.2

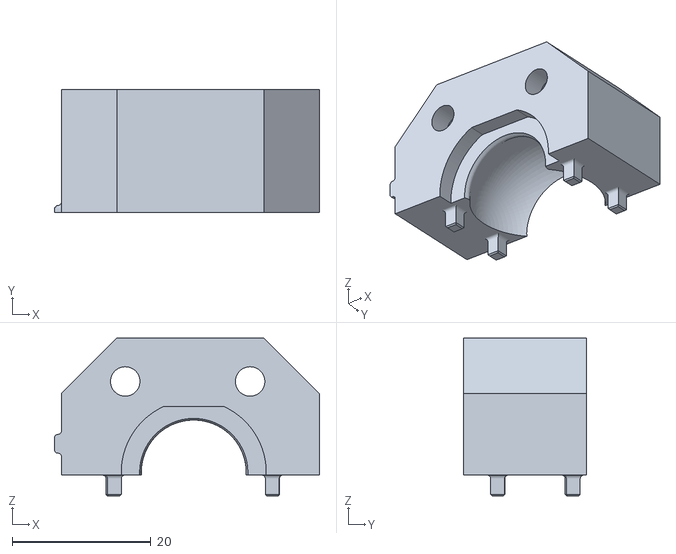
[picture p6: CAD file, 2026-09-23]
models/omega_socket2.stl
38.2 x 17.7 x 22.8

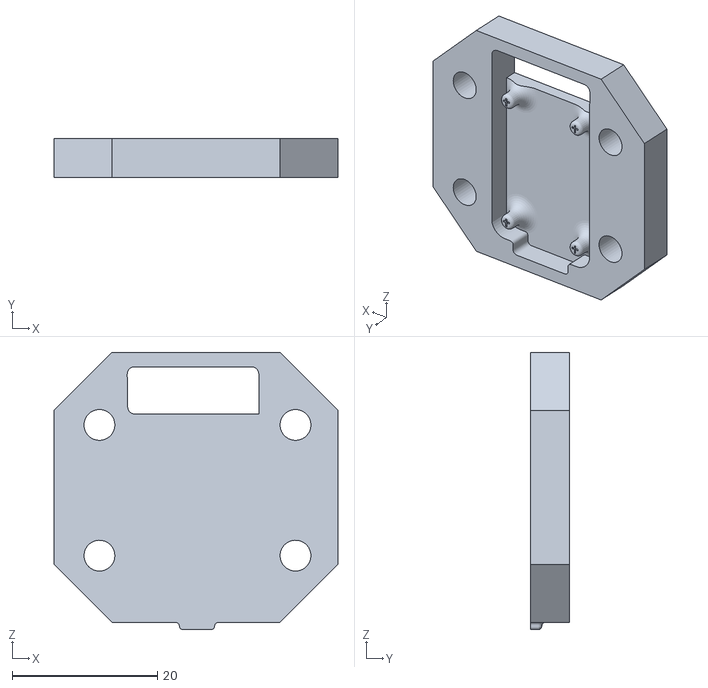
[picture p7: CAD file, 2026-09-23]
models/omega_tmag_holder.stl
39.1 x 5.35 x 38.2

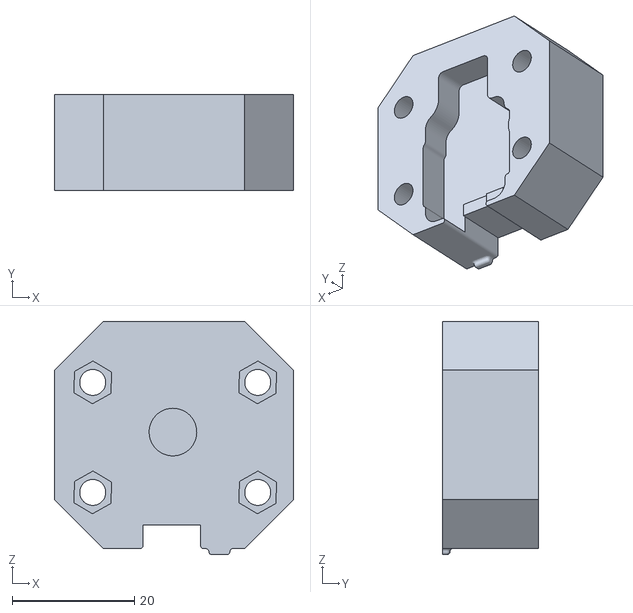
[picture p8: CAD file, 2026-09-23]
models/omega_qtpy_holder.stl
39.1 x 15.7 x 38.2

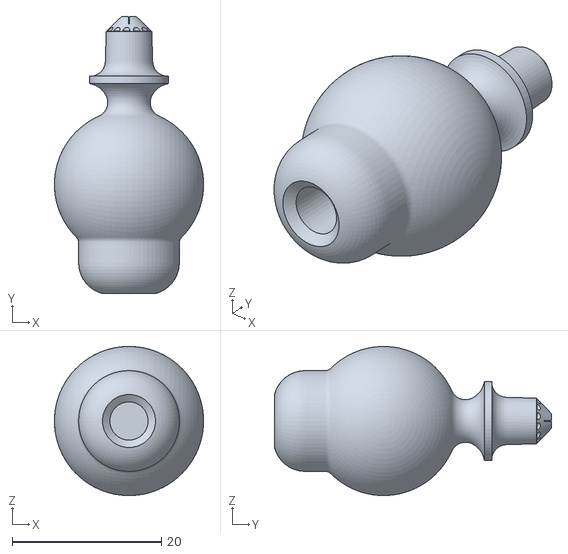
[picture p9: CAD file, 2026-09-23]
models/omega_joy.stl
20.0 x 37.1 x 20.0

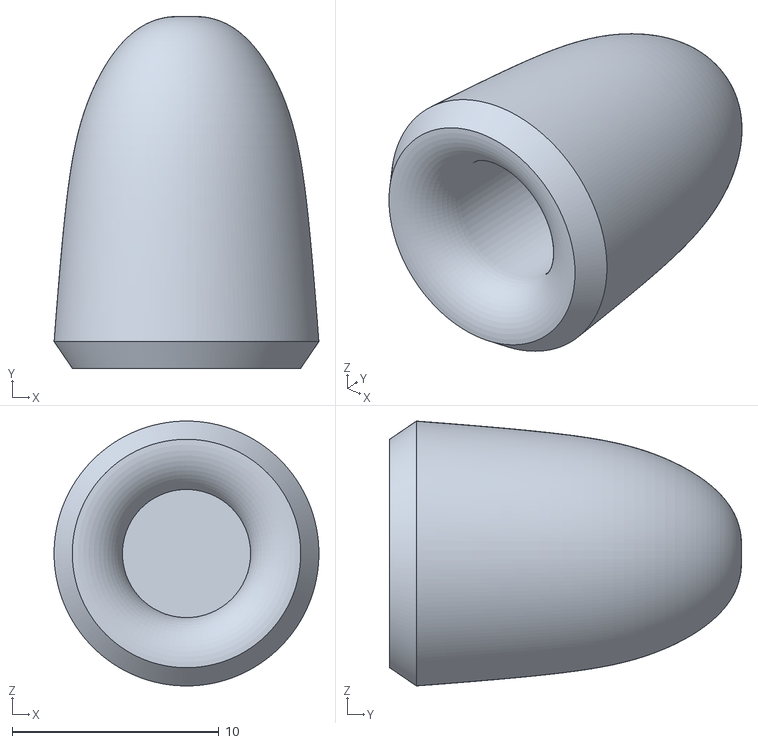
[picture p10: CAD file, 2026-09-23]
models/omega_topper.stl
12.8 x 17.0 x 12.8

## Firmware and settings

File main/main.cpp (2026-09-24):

#include <algorithm>
#include <chrono>
#include <cmath>
#include <condition_variable>
#include <cstdint>
#include <cstdio>
#include <filesystem>
#include <limits>
#include <mutex>
#include <sdkconfig.h>
#include <system_error>
#include <thread>
#include <vector>

#include "file_system.hpp"
#include "hid-rp-mouse.hpp"
#include "hid-rp.hpp"
#include "i2c.hpp"
#include "joystick.hpp"
#include "logger.hpp"
#include "omega_calibration.hpp"
#include "qtpy.hpp"
#include "task.hpp"
#include "tmag5273.hpp"
#include "usb_device.hpp"
#include "xac.hpp"

using namespace std::chrono_literals;

static constexpr uint8_t TMAG_ADDRESS = 0x35;

// Scales the normalized joystick output (-1..1) into mouse movement counts
// per polling interval. Lower this to slow the cursor down, raise it to
// speed the cursor up.
static constexpr float SENSITIVITY = 15.0f;

// Manual per-axis trim, added on top of the measured center. Use this to
// dial out mechanical misalignment (an off-center magnet, a slightly
// rotated sensor) that shows up as one direction feeling "off" even after
// a clean calibration -- adjust these, reflash, and check the printed
// "Effective center" values against your own testing. In the same raw
// magnetic units as the rest of the calibration.
static constexpr float MANUAL_OFFSET_X = 0.0f;
static constexpr float MANUAL_OFFSET_Y = 0.0f;

// ============================================================================
// Nudge click
// ============================================================================
//
//     left    -> scroll up   (held: repeated wheel-up ticks)
//     right   -> right click (held: right button down)
//     forward -> left click  (held: left button down)
//     back    -> scroll down (held: repeated wheel-down ticks)
//
// "Forward" is taken to mean pushing the stick away from the user, which is
// the same direction that already drives the cursor upward on screen, i.e.
// negative js.y(); "back" (pulling the stick toward the user) is positive
// js.y(). If a given build's mechanical/sensor orientation has the Y axis
// flipped, set INVERT_NUDGE_Y to true rather than touching the logic below.
static constexpr bool INVERT_NUDGE_Y = false;

// Amount of change between current and last movement
// to determine a nudge. Must happen within NUDGE_TIME
static constexpr float NUDGE_ENTER_THRESHOLD = 0.5f;

// Normalized magnitude the stick must fall back below before a held nudge is
// released. This is an absolute position, not a delta like
// NUDGE_ENTER_THRESHOLD, so the two aren't directly comparable: a nudge starts
// on a fast flick and stays held while the stick is past this deflection.
// Tested with both held and temp nudges.
static constexpr float NUDGE_EXIT_THRESHOLD = 0.8f;
static constexpr int NUDGE_TIME = 100;
// The polling loop below runs every 10ms. Emitting a wheel tick on every
// single poll while a scroll nudge is held would scroll far too fast, so a
// tick is only sent every Nth poll instead.
static constexpr int SCROLL_POLL_DIVIDER = 5;
static constexpr std::int8_t SCROLL_STEP = 1;

enum class NudgeDirection { NONE, LEFT, RIGHT, FORWARD, BACK };

// Classifies a normalized (x, y) stick position into one of the four cardinal
// nudge directions. Only called once the stick's magnitude has already
// crossed NUDGE_ENTER_THRESHOLD, so this only needs to pick a direction, not
// decide whether one is active.
static NudgeDirection classify_nudge(float x, float y) {
  const float effective_y = INVERT_NUDGE_Y ? -y : y;
  if (std::abs(x) >= std::abs(effective_y)) {
    return (x >= 0.0f) ? NudgeDirection::RIGHT : NudgeDirection::LEFT;
  } else {
    return (effective_y < 0.0f) ? NudgeDirection::FORWARD : NudgeDirection::BACK;
  }
}

// Where the calibration results are cached so the user doesn't have to
// recalibrate on every boot. Filename is relative to the file system's root
// (e.g. "/<partition_label>/omega_calibration.cfg") via
// OmegaCalibration::default_path().
static const std::string CALIBRATION_FILE_NAME = "omega_calibration.cfg";

// app_main() itself runs on FreeRTOS's "main" task, whose stack
// (CONFIG_ESP_MAIN_TASK_STACK_SIZE) defaults to a very small 3584 bytes.
// I2C transactions, USB/HID setup, and the printf-heavy calibration flow
// easily blow through that, so all of the real work runs on a dedicated
// espp::Task with its own generously-sized stack instead.
static constexpr size_t MAIN_TASK_STACK_SIZE_BYTES = 16 * 1024;

// Runs entirely on the dedicated "omega-stick" task (see app_main below),
// not on the small default main-task stack. Matches espp::Task's callback
// signature; m/cv are unused since this function never yields back to the
// task's own wait/dispatch loop -- it does its one-time setup and then
// never returns, spending the rest of its life in the polling loop at the
// bottom.

static bool run_omega_stick(std::mutex & /*m*/, std::condition_variable & /*cv*/) {
  // ==========================================================================
  // Create I2C bus
  // ==========================================================================
  std::error_code ec;
  auto &qtpy = espp::QtPy::get();
  qtpy.initialize_qwiic_i2c();
  auto i2c = qtpy.qwiic_i2c();
  auto device = i2c->add_device<uint8_t>(
      espp::I2c::DeviceConfig<uint8_t>{.device_address = TMAG_ADDRESS,
                                       .timeout_ms = 1000,
                                       .scl_speed_hz = 400000,
                                       .log_level = espp::Logger::Verbosity::INFO},
      ec);

  // ==========================================================================
  // Create callbacks for TMAG5273
  // ==========================================================================
  espp::TMAG5273 tmag(espp::TMAG5273::Config{

      .device_address = TMAG_ADDRESS,
      .write = espp::make_i2c_addressed_write(device),
      //.read = espp::make_i2c_addressed_read(device),
      .read_register = espp::make_i2c_addressed_read_register(device),
      .verbosity = espp::Logger::Verbosity::INFO,
      .channels = espp::TMAG5273::MagneticChannels::XYZ,

      .xy_range = espp::TMAG5273::MagneticRange::HIGH,

      .z_range = espp::TMAG5273::MagneticRange::HIGH,

      .operating_mode = espp::TMAG5273::OperatingMode::CONTINUOUS,

      .conversion_average = espp::TMAG5273::ConversionAverage::AVG_32,

      .low_noise = false,

      .auto_init = false,

  });

  // ==========================================================================
  // Initialize
  // ==========================================================================

  printf("Initializing TMAG5273...\n");

  if (!tmag.initialize(ec)) {
    printf("ERROR: TMAG5273 initialization failed: %s\n", ec.message().c_str());

    while (true) {
      std::this_thread::sleep_for(std::chrono::seconds(1));
    }
  }

  printf("TMAG5273 initialized successfully!\n\n");

#if CONFIG_OMEGA_STICK_BOOT_FLASH_WINDOW_S > 0
  // Development aid, off by default: until TinyUSB takes over the USB port,
  // the chip's USB Serial/JTAG can still reset it into the bootloader, so
  // `idf.py flash` works without holding BOOT. See main/Kconfig.projbuild.
  printf("Waiting %d s for flashing...\n", CONFIG_OMEGA_STICK_BOOT_FLASH_WINDOW_S);
  std::this_thread::sleep_for(std::chrono::seconds(CONFIG_OMEGA_STICK_BOOT_FLASH_WINDOW_S));
#endif

  // ==========================================================================
  // Calibration
  // ==========================================================================
  bool XAC_SELECTION =
      false; // TODO: Implement XAC_SELECTIon in calibration and also test and fix XAC

  const std::filesystem::path calibration_path =
      espp::OmegaCalibration::default_path(CALIBRATION_FILE_NAME);

  espp::OmegaCalibration::CenterResult center;
  espp::OmegaCalibration::RangeResult range;
  std::error_code cal_ec;

  bool have_calibration = espp::OmegaCalibration::load(center, range, calibration_path, cal_ec);
  bool run_calibration = !have_calibration;

  if (have_calibration) {
    printf("\nLoaded existing calibration.");
  }

  if (run_calibration) {
    printf("\n");
    printf("No usable cached calibration (%s); running interactive calibration.\n",
           cal_ec.message().c_str());

    printf("\n");
    printf("========================================\n");
    printf("       CENTER CALIBRATION\n");
    printf("========================================\n\n");

    espp::OmegaCalibration calibration({
        .read =
            [&tmag](float *x, float *y) {
              std::error_code read_ec;
              auto magnetic = tmag.read_magnetic(read_ec);
              if (read_ec) {
                return false;
              }
              *x = magnetic.x;
              *y = magnetic.y;
              return true;
            },
        .message = [](const std::string &text) { printf("%s\n", text.c_str()); },
        .verbosity = espp::Logger::Verbosity::INFO,
    });

    if (!calibration.center_calibration(center, cal_ec)) {
      printf("ERROR: Center calibration failed: %s\n", cal_ec.message().c_str());
      while (true) {
        std::this_thread::sleep_for(1s);
      }
    }

    printf("\n");
    printf("========================================\n");
    printf("       RANGE CALIBRATION\n");
    printf("========================================\n\n");

    if (!calibration.range_calibration(center, range, cal_ec)) {
      printf("ERROR: Range calibration failed: %s\n", cal_ec.message().c_str());
      while (true) {
        std::this_thread::sleep_for(1s);
      }
    }

    calibration.finalize_center_deadzone(center, range);

    // Manual per-axis trim (see MANUAL_OFFSET_X/Y above) is applied here,
    // on a fresh calibration, and then persisted below. A LOADED
    // calibration keeps whatever offset was already saved instead of
    // being reset to these constants every boot -- that offset might have
    // been runtime-adjusted since (via adjust_manual_offset()) and saved
    // again, and we don't want to clobber that.
    espp::OmegaCalibration::set_manual_offset(center, MANUAL_OFFSET_X, MANUAL_OFFSET_Y);

    if (!espp::OmegaCalibration::save(center, range, calibration_path, cal_ec)) {
      // Not fatal: we still have a valid in-memory calibration, it just
      // won't be cached for next boot.
      printf("WARNING: Failed to save calibration to %s: %s\n", calibration_path.c_str(),
             cal_ec.message().c_str());
    } else {
      printf("Saved calibration to %s\n", calibration_path.c_str());
    }
  }

  // ============================================================================
  // Final results
  // ============================================================================

  printf("\n");
  printf("========================================\n");
  printf("       CALIBRATION RESULTS\n");
  printf("========================================\n");

  printf("\nCENTER\n");
  printf("----------------------------------------\n");

  printf("Center X:                  %.6f\n", center.center_x);

  printf("Center Y:                  %.6f\n", center.center_y);

  printf("99%% noise radius:          %.6f\n", center.noise_radius);

  printf("Center margin:             %.2fx\n", espp::OmegaCalibration::CENTER_MARGIN);

  printf("Center deadzone:           %.6f\n", center.deadzone);

  printf("Center deadzone:           %.2f%%\n", center.deadzone * 100.0f);

  printf("Manual offset X:           %.6f\n", center.manual_offset_x);

  printf("Manual offset Y:           %.6f\n", center.manual_offset_y);

  printf("Effective center X:        %.6f\n", center.effective_center_x());

  printf("Effective center Y:        %.6f\n", center.effective_center_y());

  printf("\nRANGE\n");
  printf("----------------------------------------\n");

  printf("Usable axis radius:        %.6f\n", range.usable_radius);

  printf("Reliable max radius:       %.6f\n", range.reliable_max_radius);

  printf("Normalized max radius:     %.6f\n", range.normalized_max_radius);

  printf("Range deadzone:            %.6f\n", range.deadzone);

  printf("Range deadzone:            %.2f%%\n", range.deadzone * 100.0f);

  printf("\nRAW AXIS CALIBRATION\n");
  printf("----------------------------------------\n");

  printf("X minimum:                 %.6f\n", center.effective_center_x() + range.min_x);

  printf("X maximum:                 %.6f\n", center.effective_center_x() + range.max_x);

  printf("Y minimum:                 %.6f\n", center.effective_center_y() + range.min_y);

  printf("Y maximum:                 %.6f\n", center.effective_center_y() + range.max_y);

  // cppcheck-suppress knownConditionTrueFalse
  if (!XAC_SELECTION) { // TODO

    printf("\n");
    printf("========================================\n");
    printf("       MOUSE CONFIGURATION\n");
    printf("========================================\n\n");

    std::vector<uint8_t> hid_report_descriptor;
    {
      // WITH_WHEEL=true: nudge-click needs a relative wheel axis to scroll.
      auto raw = espp::mouse_app_report_descriptor<0, 3, true>();
      hid_report_descriptor.assign(raw.begin(), raw.end());
    }
    printf("HID mouse report descriptor: %zu bytes\n", hid_report_descriptor.size());

    espp::UsbDevice::Config usb_cfg;
    usb_cfg.manufacturer = "espp";
    usb_cfg.product = "omega-stick mouse";
    espp::UsbDevice::CdcFunction cdc_fn;
    cdc_fn.route_console = true;
    usb_cfg.cdc = cdc_fn;

    espp::UsbDevice::HidFunction hid_fn;
    hid_fn.interface_name = "omega-stick HID";
    hid_fn.report_descriptor = hid_report_descriptor;
    hid_fn.poll_interval_ms = 10;
    usb_cfg.hid = hid_fn;

    espp::UsbDevice usb(usb_cfg);

    std::error_code usb_ec;
    if (!usb.initialize(usb_ec)) {
      printf("ERROR: USB init failed: %s\n", usb_ec.message().c_str());
      while (true) {
        std::this_thread::sleep_for(1s);
      }
    }

    // Wait for the host to enumerate and open the HID endpoint.
    printf("Waiting for USB host...\n");
    for (int i = 0; i < 100 && !usb.is_hid_ready(); i++) {
      std::this_thread::sleep_for(100ms);
    }
    printf("HID ready: %s\n", usb.is_hid_ready() ? "yes" : "no");

    espp::MouseInputReport<0, 3, true> mouse;
    mouse.reset();

    espp::Joystick js(
        espp::OmegaCalibration::make_joystick_config(center, range, [&tmag](float *x, float *y) {
          std::error_code read_ec;
          auto magnetic = tmag.read_magnetic(read_ec);
          if (read_ec) {
            return false;
          }
          *x = magnetic.x;
          *y = magnetic.y;
          return true;
        }));

    std::this_thread::sleep_for(1s);

    // Corrects slow center drift while the device runs (see
    // DriftCompensator's docs in omega_calibration.hpp). Persisting the
    // drift-corrected calibration on every single nudge would wear the flash
    // for no real benefit, so it's only saved every SAVE_EVERY_N_NUDGES.
    espp::OmegaCalibration::DriftCompensator drift_compensator;
    int drift_nudge_count = 0;
    static constexpr int SAVE_EVERY_N_NUDGES = 20;

    // Current nudge-click state (see the "Nudge click" section above). This
    // persists across polling iterations/loops so a held nudge stays held.
    NudgeDirection current_nudge = NudgeDirection::NONE;
    int scroll_poll_count = 0;

    auto start = std::chrono::high_resolution_clock::now();
    js.update();
    float prev_x = js.x();
    float prev_y = js.y();
    while (true) {
      js.update();
      float raw_x = js.raw().x();
      float raw_y = js.raw().y();
      float jx = js.x();
      float jy = js.y();

      auto end = std::chrono::high_resolution_clock::now();
      auto duration = std::chrono::duration_cast<std::chrono::milliseconds>(end - start);
      const float cur_mag = std::hypot(jx, jy);

      // --- Nudge direction detection only (runs every NUDGE_TIME window) ---
      if (duration >= std::chrono::milliseconds(NUDGE_TIME)) {
        const float prev_mag = std::hypot(prev_x, prev_y);
        const float mapped_magnitude = cur_mag - prev_mag;

        if (current_nudge == NudgeDirection::NONE) {
          if (mapped_magnitude >= NUDGE_ENTER_THRESHOLD) {
            current_nudge = classify_nudge(jx, jy);
            scroll_poll_count = 0;
          }
        } else if (cur_mag <= NUDGE_EXIT_THRESHOLD) {
          current_nudge = NudgeDirection::NONE;
        }

        prev_x = jx;
        prev_y = jy;
        start = end;
      }

      // --- Per-report mouse update: runs every 10ms iteration ---
      mouse.reset_movement();
      mouse.set_button(1, current_nudge == NudgeDirection::FORWARD);
      mouse.set_button(2, current_nudge == NudgeDirection::RIGHT);

      switch (current_nudge) {
      case NudgeDirection::NONE:
        mouse.set_movement(jx * SENSITIVITY, jy * SENSITIVITY);
        break;
      case NudgeDirection::LEFT:
        scroll_poll_count++;
        if (scroll_poll_count % SCROLL_POLL_DIVIDER == 0)
          mouse.set_wheel(SCROLL_STEP);
        break;
      case NudgeDirection::BACK:
        scroll_poll_count++;
        if (scroll_poll_count % SCROLL_POLL_DIVIDER == 0)
          mouse.set_wheel(-SCROLL_STEP);
        break;
      case NudgeDirection::FORWARD:
      case NudgeDirection::RIGHT:
        break;
      }

      if (drift_compensator.update(raw_x, raw_y, cur_mag, center)) {
        espp::OmegaCalibration::apply_calibration(js, center, range);
        drift_nudge_count++;
        if (drift_nudge_count % SAVE_EVERY_N_NUDGES == 0) {
          std::error_code save_ec;
          if (!espp::OmegaCalibration::save(center, range, calibration_path, save_ec)) {
            printf("WARNING: Failed to persist drift-corrected calibration: %s\n",
                   save_ec.message().c_str());
          }
        }
      }

      auto report = mouse.get_report();
      std::error_code hid_ec;
      if (!usb.write_hid_report(0, report, hid_ec)) {
        printf("HID send failed: %s\n", hid_ec.message().c_str());
      }

      mouse.reset_movement();
      std::this_thread::sleep_for(10ms);
    }
  } else {
    using XacInput = espp::XacGamepadInputReport;

    // ------------------------------------------------------------
    // USB HID configuration
    // ------------------------------------------------------------

    std::vector<uint8_t> hid_report_descriptor;
    {
      auto raw = XacInput::get_descriptor();
      hid_report_descriptor.assign(raw.begin(), raw.end());
    }

    printf("XAC HID report descriptor: %zu bytes\n", hid_report_descriptor.size());

    espp::UsbDevice::Config usb_cfg;
    usb_cfg.manufacturer = "espp";
    usb_cfg.product = "omega-stick XAC";

    espp::UsbDevice::CdcFunction cdc_fn;
    cdc_fn.route_console = true;
    usb_cfg.cdc = cdc_fn;

    espp::UsbDevice::HidFunction hid_fn;
    hid_fn.interface_name = "omega-stick XAC";
    hid_fn.report_descriptor = hid_report_descriptor;
    hid_fn.poll_interval_ms = 10;

    usb_cfg.hid = hid_fn;

    espp::UsbDevice usb(usb_cfg);

    std::error_code usb_ec;

    if (!usb.initialize(usb_ec)) {
      printf("ERROR: USB init failed: %s\n", usb_ec.message().c_str());

      while (true) {
        std::this_thread::sleep_for(1s);
      }
    }

    printf("Waiting for USB host...\n");

    for (int i = 0; i < 100 && !usb.is_hid_ready(); i++) {
      std::this_thread::sleep_for(100ms);
    }

    printf("HID ready: %s\n", usb.is_hid_ready() ? "yes" : "no");

    // ------------------------------------------------------------
    // XAC input report
    // ------------------------------------------------------------

    XacInput xac_input_report;
    xac_input_report.reset();

    // ------------------------------------------------------------
    // Joystick
    // ------------------------------------------------------------

    espp::Joystick js(
        espp::OmegaCalibration::make_joystick_config(center, range, [&tmag](float *x, float *y) {
          std::error_code read_ec;

          auto magnetic = tmag.read_magnetic(read_ec);

          if (read_ec) {
            return false;
          }

          *x = magnetic.x;
          *y = magnetic.y;

          return true;
        }));

    std::this_thread::sleep_for(1s);

    // ------------------------------------------------------------
    // Drift compensation
    // ------------------------------------------------------------

    espp::OmegaCalibration::DriftCompensator drift_compensator;

    int drift_nudge_count = 0;

    static constexpr int SAVE_EVERY_N_NUDGES = 20;

    // ------------------------------------------------------------
    // HID polling loop
    // ------------------------------------------------------------

    while (true) {

      js.update();

      const float raw_x = js.raw().x();
      const float raw_y = js.raw().y();
      const float mapped_magnitude = std::hypot(js.x(), js.y());

      if (drift_compensator.update(raw_x, raw_y, mapped_magnitude, center)) {

        espp::OmegaCalibration::apply_calibration(js, center, range);

        drift_nudge_count++;

        if (drift_nudge_count % SAVE_EVERY_N_NUDGES == 0) {
          std::error_code save_ec;
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
extern "C" void app_main(void) {
  // Keep the task object alive for the lifetime of the program -- if it
  // were a local variable here, it would be destroyed (stopping the task)
  // the moment app_main() fell through to the sleep loop below.

  static auto task = espp::Task::make_unique(espp::Task::Config{
      .callback = run_omega_stick,
      .task_config =
          {
              .name = "omega-stick",
              .stack_size_bytes = MAIN_TASK_STACK_SIZE_BYTES,
          },
      .log_level = espp::Logger::Verbosity::INFO,
  });
  task->start();

  // app_main()'s own task can now stay small and idle forever; all the
  // real work happens on the "omega-stick" task above.
  while (true) {
    std::this_thread::sleep_for(1s);
  }
}

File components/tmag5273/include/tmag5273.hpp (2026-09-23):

#pragma once

#include <cstdint>
#include <system_error>

#include "base_component.hpp"
#include "base_peripheral.hpp"

namespace espp {

/**
 * @brief Driver for the Texas Instruments TMAG5273 3-axis Hall-effect sensor.
 *
 * @details
 * Header-only espp driver for the TMAG5273 using the ESP-IDF I2C master API.
 *
 * The API is intentionally modeled after the Adafruit TMAG5273 library while
 * using espp's BasePeripheral abstraction for register access and I2C locking.
 */
class TMAG5273 : public BasePeripheral<> {
public:
  // ==========================================================================
  // Device constants
  // ==========================================================================

  static constexpr uint8_t DEFAULT_ADDRESS = 0x35;

  // ==========================================================================
  // Register addresses
  // ==========================================================================

  static constexpr uint8_t DEVICE_CONFIG_1 = 0x00;
  static constexpr uint8_t DEVICE_CONFIG_2 = 0x01;
  static constexpr uint8_t SENSOR_CONFIG_1 = 0x02;
  static constexpr uint8_t SENSOR_CONFIG_2 = 0x03;

  static constexpr uint8_t X_THR_CONFIG = 0x04;
  static constexpr uint8_t Y_THR_CONFIG = 0x05;
  static constexpr uint8_t Z_THR_CONFIG = 0x06;
  static constexpr uint8_t T_CONFIG = 0x07;
  static constexpr uint8_t INT_CONFIG_1 = 0x08;

  static constexpr uint8_t MAG_GAIN_CONFIG = 0x09;
  static constexpr uint8_t MAG_OFFSET_CONFIG_1 = 0x0A;
  static constexpr uint8_t MAG_OFFSET_CONFIG_2 = 0x0B;

  static constexpr uint8_t I2C_ADDRESS = 0x0C;
  static constexpr uint8_t DEVICE_ID = 0x0D;
  static constexpr uint8_t MANUFACTURER_ID_LSB = 0x0E;
  static constexpr uint8_t MANUFACTURER_ID_MSB = 0x0F;

  static constexpr uint8_t T_MSB_RESULT = 0x10;
  static constexpr uint8_t T_LSB_RESULT = 0x11;

  static constexpr uint8_t X_MSB_RESULT = 0x12;
  static constexpr uint8_t X_LSB_RESULT = 0x13;

  static constexpr uint8_t Y_MSB_RESULT = 0x14;
  static constexpr uint8_t Y_LSB_RESULT = 0x15;

  static constexpr uint8_t Z_MSB_RESULT = 0x16;
  static constexpr uint8_t Z_LSB_RESULT = 0x17;

  static constexpr uint8_t CONV_STATUS = 0x18;

  static constexpr uint8_t ANGLE_RESULT_MSB = 0x19;
  static constexpr uint8_t ANGLE_RESULT_LSB = 0x1A;

  static constexpr uint8_t MAGNITUDE_RESULT = 0x1B;
  static constexpr uint8_t DEVICE_STATUS = 0x1C;

  // ==========================================================================
  // Conversion status bits
  // ==========================================================================

  static constexpr uint8_t STATUS_RESULT_READY = 0x01;
  static constexpr uint8_t STATUS_DIAG_FAIL = 0x02;
  static constexpr uint8_t STATUS_POR = 0x10;

  // ==========================================================================
  // Operating modes
  // ==========================================================================

  enum class OperatingMode : uint8_t {
    STANDBY = 0x00,
    SLEEP = 0x01,
    CONTINUOUS = 0x02,
    WAKE_SLEEP = 0x03
  };

  // ==========================================================================
  // Magnetic channels
  // ==========================================================================

  enum class MagneticChannels : uint8_t {
    OFF = 0x00,
    X = 0x01,
    Y = 0x02,
    XY = 0x03,
    Z = 0x04,
    ZX = 0x05,
    YZ = 0x06,
    XYZ = 0x07,

    // Angle measurement combinations
    XYX = 0x08,
    YXY = 0x09,
    YZY = 0x0A,
    XZX = 0x0B
  };

  // ==========================================================================
  // Magnetic range
  //
  // TMAG5273A1:
  //   LOW  = ±40 mT
  //   HIGH = ±80 mT
  //
  // TMAG5273A2:
  //   LOW  = ±133 mT
  //   HIGH = ±266 mT
  // ==========================================================================

  enum class MagneticRange : uint8_t { LOW = 0, HIGH = 1 };

  // ==========================================================================
  // Angle conversion
  // ==========================================================================

  enum class AngleConversion : uint8_t {
    OFF = 0x00,
    ANGLE_XY = 0x01,
    ANGLE_YZ = 0x02,
    ANGLE_XZ = 0x03
  };

  // ==========================================================================
  // Conversion averaging
  // ==========================================================================

  enum class ConversionAverage : uint8_t {
    AVG_1 = 0x00,
    AVG_2 = 0x01,
    AVG_4 = 0x02,
    AVG_8 = 0x03,
    AVG_16 = 0x04,
    AVG_32 = 0x05
  };

  // ==========================================================================
  // Data structures
  // ==========================================================================

  struct MagneticData {
    float x{0.0f};
    float y{0.0f};
    float z{0.0f};
  };

  struct RawMagneticData {
    int16_t x{0};
    int16_t y{0};
    int16_t z{0};
  };

  // ==========================================================================
  // Configuration
  // ==========================================================================

  struct Config {

    uint8_t device_address = DEFAULT_ADDRESS;
    BasePeripheral::write_fn write;
    // BasePeripheral::read_fn read;
    BasePeripheral::read_register_fn read_register;
    espp::Logger::Verbosity verbosity = espp::Logger::Verbosity::INFO;

    MagneticChannels channels{MagneticChannels::XYZ};

    MagneticRange xy_range{MagneticRange::HIGH};

    MagneticRange z_range{MagneticRange::HIGH};

    OperatingMode operating_mode{OperatingMode::CONTINUOUS};

    ConversionAverage conversion_average{ConversionAverage::AVG_1};

    bool low_noise{false};

    bool auto_init{true};
  };

  // ==========================================================================
  // Constructor
  // ==========================================================================

  explicit TMAG5273(const Config &config)
      : BasePeripheral({.address = config.device_address,
                        .write = config.write,
                        //.read = config.read,
                        .read_register = config.read_register},
                       "TMAG5273", config.verbosity)
      , channels_(config.channels)
      , xy_range_(config.xy_range)
      , z_range_(config.z_range)
      , operating_mode_(config.operating_mode)
      , conversion_average_(config.conversion_average)
      , low_noise_(config.low_noise) {

    if (config.auto_init) {
      std::error_code ec;
      initialize(ec);
    }
  }

  ~TMAG5273() = default;

  // ==========================================================================
  // Initialization
  // ==========================================================================

  bool initialize(std::error_code &ec) {
    if (!is_connected(ec)) {
      ec = std::make_error_code(std::errc::not_connected);
      logger_.error("TMAG5273 not connected or no response from device.");
      return false;
    }
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

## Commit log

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2026-09-04 Add v1 product requirements document and supporting research
    Adds docs/PRD.md, a one-page product requirements document, together with
    the detailed specification and the research it was built from.
    docs/PRD.md product definition: problem, users, positioning,
    open source rationale, goals, scope, user stories,
    success metrics, claims constraints
    docs/requirements.md full functional and non-functional specification,
    hardware interface contract, host compatibility
    matrix, known driver defects
    docs/decisions.md product decisions with rationale, open decisions
    docs/compliance.md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
2026-09-04 Run static analysis on PRs into slash-named branches
    The workflow filtered on `branches: ["*"]`. GitHub branch globs treat `*` as
    matching any characters except `/`, so any pull request whose base branch
    contained a slash skipped static analysis entirely. PR #6, based on
    chore/oss-community-prep, ran only two checks where a PR into main ran three.
    It fails silently rather than loudly, and static_analysis is a required check
    on main, so a future protected branch with a slash in its name would have
    blocked forever waiting for a check that never runs.
2026-09-04 Remove medical-device regulatory analysis and fix dangling references
    The docs walked through how the product's marketing language keeps it out of a
    Class II medical-device classification, including the conditions under which an
    exemption could be voided. On a public repository that reads as a record of
    engineering claims to avoid regulation, and it is not something this project
    needs to publish in order to state its position.
    Removed:
    - The FDA and medical device status section of research/04, and with it the
    510(k), 21 CFR 820, MDR and exemption-voiding analysis. The file no longer
    covers regulatory status, so it is renamed to 04-funding-and-compliance.md
    and its sections renumbered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
2026-09-04 Resolve the actuation force decision (D12) and align the docs to it
    Three documents disagreed about whether adjustable actuation force was settled.
    decisions.md called it the only open item upstream of hardware, while PRD.md
    section 9 and requirements.md HW-1 already published "adjustable 5 to 25 gf" as
    a requirement, and README.md led with a flat "under 10 grams" as the product's
    differentiator.
    Settled in the direction the evidence and the majority of the documents already
    pointed: force is adjustable across roughly 5 to 25 gf, defaulting below 10.
    Celtic Magic and mo-vis, the two vendors operating at this end of the range,
    both report that too-light is a real failure mode, so the usable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
2026-09-04 Add brand assets
    Vector marks for Omega Stick, traced from the reference artwork with potrace
    and finished by hand.
    The omega outline is 95 cubic Bezier curves with no straight segments. An
    earlier pass used cv2.approxPolyDP, which produces a polygon rather than
    curves, and read as visibly faceted. Worth recording that raw potrace was
    worse still: it produced 852 curves and a bumpy edge because it traced every
    pixel stair-step in the source bitmap. Blurring the bitmap before tracing cut
    it to 95 and made it smooth, so more curves was the wrong instinct.
    The wordmark is built from geometric primitives rather than an outlined font,
    so it does not depend on a typeface being installed anywhere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
2026-09-05 Add scene.html, the brand scene as a live hero
    Draws the mark and a perspective floor in HTML and CSS, with no images, no JavaScript and no webfont. The mark is constructed from ellipse arcs rather than the trace, so it is symmetric about its centre; the floor is one 3D-transformed plane whose background carries the colour and whose mask carries the lines, which lets the grid be lit by a gradient and lets the drift move through the perspective correctly.
    The grid holds still by default. Perspective squares the line weight, so a depth line lands at --lw-z * cos(tilt) * (1 - u)^2 and falls under a pixel wide past u = 0.61, and a sub-pixel line cannot move without its coverage stepping. Soften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
2026-09-05 Generate the still scenes from scene.html's geometry
    scene.svg had drifted badly from scene.html: the mark was 55.5% of the frame width against the HTML's 38.9%, its feet sat on the horizon rather than in front of it, and the grid ran at half the pitch. Measured by rendering both, not read off the source.
    Rather than redraw it, build-scene.py derives the camera, framing and palette from the same constants scene.html uses, so the two cannot drift again without someone editing one and not rerunning the other. It also emits scene-mark.svg (the same canvas with the floor removed) and omega-neon.svg (the mark alone, transparent, drop-in for omega.svg). Output is deterministic and the trace is re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
2026-09-05 Document the scene files and how they are generated
    Records what is generated and from where, the data attributes and dials scene.html exposes, and the constraints found while building: omega-neon.svg needs a dark ground, scene.html needs data-intro="off" to screenshot, and the plane's colour stops are tied to --depth.
    Also corrects two claims that had gone stale: the traced outline is carried by eight SVGs rather than six, and the gradients are no longer uniformly userSpaceOnUse now that the generated files use objectBoundingBox to survive their transformed groups.
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2026-09-06 Redraw the wordmark and generate it from a script
    The old wordmark was built from axis-aligned rectangles: every letter a set of
    boxes on a fixed pitch, hard corners throughout, the O a plain ring. Beside the
    mark, which is 95 Bezier curves and reads as a soft neon tube, it looked like a
    different brand's type set next to someone else's symbol.
    It is drawn in the mark's own language now: straight lines and arcs, stroked
    with round caps and joins at 17% of the cap height, so the round terminal is the
    same tube the mark reads as and the lockup looks like one drawing rather than a
    symbol with a caption. wordmark.svg, wordmark-mono.svg and lockup.svg are
    generated by build-wordmark.py, which re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
2026-09-23 Stop cppcheck failing on style preferences and the XAC mode switch
    useStlAlgorithm is a style opinion, not a defect, so suppress it project-wide.
    knownConditionTrueFalse stays on because it catches real dead code; the XAC
    branch is a deliberate compile-time switch, so suppress it at that one site.
    [main.cpp]
2026-09-23 Tidy up after the mouse firmware merge
    Put the 15 s boot delay behind a menuconfig option that defaults to 0. It
    exists so idf.py can flash the board before TinyUSB takes the USB port, but
    every user was waiting 15 s at power-on for it.
    Correct the NUDGE_EXIT_THRESHOLD comment, which called 0.8 lower than 0.5.
    The two thresholds measure different things, so say that instead.
    Set ESPP_I2C_USE_NEW_API to y. kconfgen ignored the old value of 1 with a
    warning; the new API was already the default, so behavior is unchanged.
    Move the flash-size note onto its own line and ignore .vscode/, whose
    contents are per-machine.
    [main.cpp]
2026-09-26 xac doesn't work yet, but there is rudimentarry calibration and flashing
    [partitions.csv]
2026-09-27 Add host-side unit tests for the calibration component
    Compiles omega_calibration, omega_store and calibration_service on a
    desktop toolchain against small stand-ins for the ESP-IDF-dependent espp
    pieces and the real, version-pinned espp stream_frame/dispatcher headers.
    Covers save/load round-trips, OmegaStore setters and callbacks, and the
    CalibrationService request/reply protocol through the real frame parser.
    Three tests are marked XFAIL to document known bugs (SET_INPUT_MODE reply
    ordering, same-mode restart, manual offset clobbered by set_calibration);
    they flip the run red once fixed so the marker gets removed.
    Adds a host_tests workflow that runs them on every pull request.
2026-09-30 Add host tests for the XAC HID report byte layout
    Build components/xac/include/xac.hpp against the pinned espp/hid-rp 1.3.3
    component archive (always downloaded and hash-checked, never taken from
    managed_components/) and check the bytes get_report() produces against the
    order the report descriptor declares.
    Three of the tests are XFAIL: espp's GamepadInputReport::get_report() and
    set_data() skip a fixed 2 bytes, which is the report ID plus alignment
    padding for the default uint16_t axes but one byte too many for the uint8_t
    axes XacInputReport uses. X is dropped, every field shifts down a slot and RZ
    reads 0, which matches the drift and X-only movement seen on the Xbox
    Adaptive Controller.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
2026-10-10 Fix calibration console gaps and route its USB traffic through DispatcherWorker
    - Console: add manual center offset controls (SET_MANUAL_OFFSET had no UI),
    and make Apply actually re-read state (refreshState() bailed out while the
    Apply handler held `busy`).
    - Firmware: give each USB byte stream (vendor, CDC) a DispatcherWorker so
    replies are written from the worker task instead of the TinyUSB receive
    callback, where UsbDevice writes fail fast, and so module-0xFF discovery is
    answered. Replace the UNVERIFIED comment: the UsbDevice names match espp
    v1.3.3.
    - Set the USB VID/PID explicitly and point the console's WebUSB filter at it;
    the page defaulted to 0x0d36 (the coredump exa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
2026-10-10 Document the calibration console and the Windows toolchain setup
    - Add components/omega_calibration/README.md: how to open and connect the
    console, what each section changes, and how the firmware wires it to USB.
    - README: point to the console, note the ESP-IDF version dependencies.lock
    was resolved against, and update the component layout line.
    - CONTRIBUTING: one-command ESP-IDF install on Windows with EIM.
    - tests/host/README: document the std::bit_cast build failure on Windows
    toolchains and the force-include workaround.
    - main.cpp: the wiring comment now names the locked espp/dispatcher version
    (1.3.5), not 1.3.3.
2026-10-10 Send the input-mode OK before switching modes
    main.cpp's on_mode_changed saves and calls esp_restart(), and
    CalibrationService ran it inside handle_frame_locked(), before the OK
    reply was built. The console never got the OK and reported a timeout for
    a switch that worked. The service now records the accepted mode and
    applies it after the reply has been sent.
    OmegaStore::set_input_mode() also ignores the mode that is already
    active, so re-selecting it from the console no longer saves and restarts
    the device.
    Both XFAIL tests for these bugs are now plain tests. The header's
    comments drop their em dashes and the stale \snippet reference.
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2026-10-10 Add software-only test coverage: real espp host build, web, golden frames, fuzzing, and a testable control core
    Host tests now compile against the real espp components pinned to dependencies.lock instead of hand-written stubs, and run with warnings as errors, ASan/UBSan and coverage in CI (gcc, clang, MSVC). New suites cover the calibration math, the drift compensator, the TMAG5273 driver on a fake I2C register map, the mouse report, both HID report descriptors, and the control loop.
    The control loop in main.cpp moves into components/omega_control, a pure header the host tests drive through injected time and a small Ports interface. Three deliberate behaviour changes come with it: a neutral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
2026-10-10 Add USB firmware updates with automatic rollback and revert
    Port the OTA transport from ota-implementation (d5ff600) without the
    unrelated calibration, mouse and XAC changes that commit bundled: two
    app slots (ota_0/ota_1), espp/ota, the OTA_BEGIN/DATA/FINISH/ABORT,
    RESTART, GET_FW_INFO and MARK_VALID messages, and the console's firmware
    update section. Existing message IDs keep their values.
    Confirm a new image automatically. With app rollback enabled a freshly
    installed image stays PENDING_VERIFY until the app says otherwise, and
    d5ff600 only did that from a console button, so any reset before the
    button was pressed reverted the update. FirmwareHealthCheck marks the
    image valid once USB H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
2026-10-10 Test and document firmware updates, revert and versioning
    Host tests: stubs for espp/ota, esp_app_desc.h and esp_ota_ops.h so
    calibration_service.hpp compiles on the host, plus tests for FW_INFO
    (including the previous-slot fields), the upload flow, every REVERT
    error path and its happy path. The espp pins move to 1.3.6 to match
    dependencies.lock. The two XAC report-layout tests that were marked
    XFAIL already passed (xac.hpp's own get_report() sidesteps the base
    class offset bug) and failed the run as XPASS, so they are plain tests
    now; their results are identical on hid-rp 1.3.3 and 1.3.6.
    Docs: docs/firmware-updates.md covers the partition layout, updating
    from the console, the health che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
2026-10-10 Roll back a pending image when init fails, and respect a manual confirm
    A fatal sensor, calibration or USB init failure on an image still pending
    verification now marks it invalid and reboots into the previous firmware,
    instead of halting on the broken image until someone power-cycles it. The
    OTA engine is created before TMAG init so every failure branch can reach it.
    The health check re-reads the running image's state on each tick, so a
    console MARK_VALID before the deadline stops the automatic check instead of
    being undone by a later rollback.
    FirmwareHealthCheck moves to firmware_health_check.hpp with an injectable
    clock so the host tests can cover both cases.
2026-10-10 Release an abandoned firmware upload without a restart
    Disconnecting from the console mid-upload now sends OTA_ABORT before the
    link closes. On the device, OTA_BEGIN and REVERT from the link that owns a
    stale session abort it and carry on, and the polling loops drop an upload
    that has had no OTA traffic for 30 s, which covers a pulled cable or a
    closed tab. A session owned by the other link is still refused.
2026-10-10 Rebuild the version on version bumps and commits; fix cppcheck notices
    Setting PROJECT_VER before project() skips ESP-IDF's version.txt reader, so
    nothing told CMake to re-run when the file changed and an incremental build
    kept the old version. version.txt, git's HEAD and the current branch ref are
    now configure dependencies. The .dirty suffix still reflects the last
    configure, as documented.
    The esp_ota_ops.h stub used std::memset, which cppcheck rejects when it
    parses .h files as C. Also return the stub's labels by const reference.
    Document interrupted uploads and incremental versioning in
    firmware-updates.md.
2026-10-10 Record what the sibling ATDev and RAMMP firmware repos teach us
    Survey of fifteen firmware repositories, compared against this repo. The
    headline is that the TMAG5273 read path holds its last output when a read
    fails, so a sensor fault while deflected keeps the host moving.
2026-10-10 Center the stick on a sensor fault instead of holding the last deflection
    espp::Joystick::update() keeps its previous output when get_values fails,
    so a TMAG5273 that dropped off the bus while deflected kept the host
    moving in that direction until the device was unplugged (SEN-6).
    OmegaCalibration::SensorFaultMonitor trips after three consecutive failed
    reads or a long run of bit-identical readings, holds the output neutral
    until ten good reads, and latches the first fault for later status
    reporting. Both the mouse and XAC loops feed it and send an idle report
    while it is tripped; drift correction and nudge detection skip those
    ticks. Rules and rationale are D13 in docs/decisions.md; host t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
2026-10-10 Make the host tests build with clang and promote the XAC report tests
    hid-rp 1.3.3's short_item.hpp uses std::bit_cast without including <bit>;
    GCC's <array> happens to pull it in, clang with the MSVC STL does not.
    The three xac_* layout tests have passed since XacInputReport gained its
    get_report() override, so the runner reported XPASS and failed the suite.
    They are ordinary tests again, and the full-right assertion now expects
    center + range (254 for 8-bit axes), which is what hid-rp produces.
2026-10-10 Log the reset reason and a boot counter across boots
    A core dump only exists for a panic. Brownouts, watchdog resets and short
    boot loops left nothing behind. ResetLog keeps the last sixteen reasons in
    a small file next to the calibration, flags the abnormal ones, and main.cpp
    records this boot's reason before anything that can fail, then prints the
    abnormal history. Rules and next steps are D16 in docs/decisions.md.
2026-10-10 Pin the espp components to the release the firmware is tested against
    The manifest still carried the template's idf >=4.1.0 and >=1.0 floors.
    Tightening them to floors was not enough: the component manager re-solves
    to the newest matching release whenever the manifest changes and ignores
    the lock while doing so, and that pulled in espp 1.3.7, whose
    DispatcherModuleInfo gained a field the -Werror build rejects.
    Every espp component, including the transitive ones, is now pinned with ==
    so a re-solve reproduces the tested set, and the manifest says how to bump
    them together. The lock changes only its manifest hash.
2026-10-10 Pin GitHub Actions to commit SHAs and let Dependabot move them
    A moved or hijacked tag can no longer change what CI runs on a public
    repository that ships firmware. StaticAnalysis was tracking master and is
    pinned to the commit current today. Dependabot keeps the pins fresh weekly.
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2026-10-10 Make the reset log save atomic and record the boot before sensor init
    save() now writes a temporary sibling file and renames it over the log, so a reset mid-save cannot leave an empty history; load() falls back to a complete temporary file if the log is missing. The boot is recorded at the start of startup, right after the filesystem mounts, so a sensor failure no longer skips it. Also drop the redundant string_view construction cppcheck flagged.
2026-10-10 Revert to the other slot when a confirmed image crash-loops
    The bootloader's rollback only covers a pending image. Once an image has
    confirmed itself, a bug that panics on every boot would leave the device
    rebooting forever until someone re-flashed over serial.
    FirmwareHealthCheck::revert_if_crash_looping() runs at boot with this
    slot's recent resets: three crashes in a row (panic, watchdog, lockup;
    brownouts excluded) and an app image in the other slot switch the boot
    partition. The caller restarts. A pending image is left to the
    bootloader. Host tests cover the streak rule, the pending case, a missing
    other image and a failed switch. The main.cpp wiring follows once the
    reset log (#22) is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
2026-10-10 Give the frame fuzzer the OTA header stubs
    calibration_service.hpp includes ota.hpp since the USB firmware updates merged, and the omega_frame_fuzz target had only omega_calibration/include on its path, so the fuzz job failed with 'ota.hpp' file not found. Add tests/host/stubs, which the host tests already use for the same headers.
2026-10-10 Show sensor faults and the reset log on the console, and watch the conversion counter
    GET_DIAGNOSTICS (0x5F) returns the SensorFaultMonitor state the control
    loop reports through EspPorts::sensor_fault_changed (fault now, first
    fault, count) plus the ResetLog, and the calibration console gets a
    Diagnostics panel for it. The reply is variable-length and keeps the
    newest resets when the list would not fit in one frame. omega_protocol.js
    gains decodeDiagnostics(), the HTML copy is regenerated, and the golden
    frames include the new request and reply.
    The TMAG5273 driver now reads CONV_STATUS in the same burst as X, Y and Z
    (7 bytes instead of 6) and exposes its 3-bit conversion counter through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
2026-10-10 Feed the crash-loop revert from the reset log at boot
    Each reset entry's name now carries the slot it happened in
    ("panic (ota_0)"), so the check sees this image's boots only and a
    crash in the other slot cannot bounce the device straight back. The
    check runs as soon as the OTA engine exists, before sensor init, since a
    crash-looping image may not get further than that.
    revert_if_crash_looping() takes any indexable range of bools rather than
    a std::span, because std::vector<bool> is what the caller naturally
    builds.
2026-10-10 Address review findings on the diagnostics and stuck-check work
    - XAC_SENSOR_FAULT_CONFIG doubles stuck_after_stale_conversions too, so
    the 5 ms loop keeps the same 500 ms window as the mouse loop.
    - StickSample::conversion_count is optional: producers without a counter
    (host fakes, tests) no longer look like a frozen sensor.
    - The monitor's streaks saturate at their thresholds instead of
    overflowing after months of a frozen sensor.
    - The console's Diagnostics panel uses the stylesheet's warn-text class.
    - The security workflow's concurrency group includes the event name, so
    a scheduled scan and a push scan do not cancel each other.
    - No em dashes in the new protocol comment lines.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
2026-10-10 Charge each reset to the boot it ended, and never retry a rejected slot
    Review findings on the crash-loop revert:
    - The reset reason recorded at boot N ended boot N-1, so it belongs to
    that boot's slot. Charging it to boot N's slot blamed a confirmed
    image for the other image's crash after every bootloader rollback and
    would have bounced the device between slots forever. The derivation
    now lives in FirmwareHealthCheck::crashes_while_running(), with a host
    test that replays that exact sequence.
    - An other slot the bootloader or health check already marked INVALID or
    ABORTED is not re-armed; the console's REVERT stays the deliberate way.
    - The check runs before any peripheral setu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
2026-10-11 Make the console's after-change messages truthful, and never act on a reply the host did not get
    Issue #27.
    Console:
    - A mode switch no longer reads the state back. The device saves and
    restarts right after its OK, so that GET_STATE always timed out and the
    console logged a failure for a switch that worked. It now says the
    device is restarting and to reconnect.
    - Clicking the mode that is already active says so instead of claiming a
    switch (and sends nothing).
    - The read-back after an applied SET_* has its own error path: a failed
    refresh is reported as a refresh failure, not as the setting failing.
    Firmware:
    - send_fn returns bool. If the transport refuses the reply (write_vendo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
2026-10-11 Let the device say whether a mode switch happened, and gate every reboot on a queued reply
    Review findings on the first version:
    - The console decided between "already in this mode" and "switching" from
    its cached state, which can be stale after a reconnect or a change over
    the other link. The OK for SET_INPUT_MODE now carries 1 (switching, the
    device restarts after the reply) or 0 (already active), the console
    reports that, and it forgets its cached state on connect and disconnect.
    - RESTART, REVERT and OTA_FINISH rebooted from a detached thread whether
    or not their OK was queued. They go through the same after_reply_ hook
    as the mode switch, so a refused reply never leads to a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

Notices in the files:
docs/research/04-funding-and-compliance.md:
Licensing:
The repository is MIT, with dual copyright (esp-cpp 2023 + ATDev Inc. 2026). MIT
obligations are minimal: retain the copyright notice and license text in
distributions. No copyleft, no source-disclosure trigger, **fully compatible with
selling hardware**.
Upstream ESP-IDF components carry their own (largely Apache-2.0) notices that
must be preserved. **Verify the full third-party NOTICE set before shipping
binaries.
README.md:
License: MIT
